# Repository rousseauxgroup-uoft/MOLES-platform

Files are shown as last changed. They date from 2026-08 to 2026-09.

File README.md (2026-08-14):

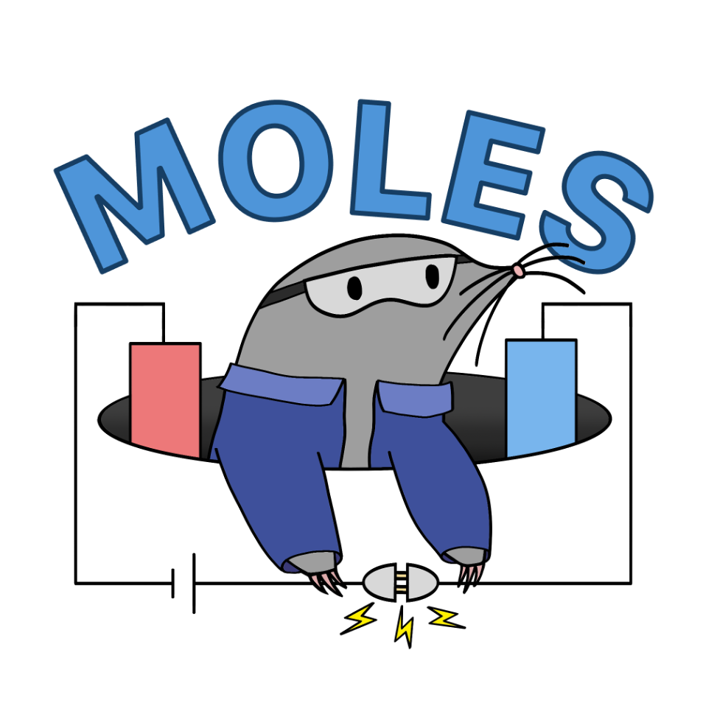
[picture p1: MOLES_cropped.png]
Moley the Mole, the mascot for MOLES


# MOLES
**M**odular **O**pen-source **L**aboratory for **E**lectrochemistry **S**creening

An affordable platform for small-scale electrosynthesis screening, enabled by an open-source potentiostat designed by the Acceleration Consortium and Matter Lab the University of Toronto (*Device*, **2025**, *3*, 100567, doi: 10.1016/j.device.2024.100567).

## Quickstart
- Clone or fork the MOLES repository.
- In your environment, run: ```pip install .``` in the terminal to install the package.
- Run the launcher with command: ```moles``` (or ```python -m moles```)
  - Shows every registered potentiostat with its live status (free, or in use by which app/experiment/user) and launches the apps below as independent processes
- Run electrolysis UI with command: ```moles-electrolysis```
  - Supported methods: **constant current**, **constant potential**, **alternating current** (up to 7 Hz via PID current control), and **alternating polarity** (up to 50 Hz via autonomous potential control)
- Run electroanalysis UI with command: ```moles-electroanalysis```
  - Tabbed interface for **cyclic voltammetry (CV)**, **differential pulse voltammetry (DPV)**, and an **analysis** workspace for overlaying, offsetting, smoothing, and labelling saved voltammograms

## More information
Check the [MOLES wiki](https://github.com/rousseauxgroup-uoft/MOLES-platform/wiki/MOLES-Wiki-Home) for more information regarding potentiostat ordering, hardware components, and other useful knowledge!

### Running multiple apps at once
MOLES apps can run in parallel on one machine: for example, an electrolysis experiment
on boards A–H while someone else runs CVs on board I. Serial ports are only
opened while an experiment is running, and each running experiment holds a
*claim* on its board (visible in the launcher and in each app's status
column), so starting an experiment on a board that is already in use is
refused with a message naming the current holder instead of interrupting it.
Claims left behind by a crashed app are detected automatically; the launcher's
"Force Release" button clears one manually if ever needed.

Much thanks to Sergio Pablo-García, Ángel García, Gun Deniz Akkoc, Malcolm Sim, Yang Cao, Maxine Somers, Chance Hattrick, Naruki Yoshikawa, Dominik Dworschak, Han Hao, and Alán Aspuru-Guzik for designing the first-generation open potentiostat platform that MOLES is based off.

*Note: Generative AI (Claude Code, Google Gemini, OpenAI GPT-5 Codex) was used for this project to assist with writing code.*

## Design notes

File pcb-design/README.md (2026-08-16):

## Ordering guide
Refer to the MOLES wiki.

## Board specifications
- 2 layers, FR4, 0.062" ±10%, ENIG (2 µ") surface finish, 1 oz outer copper
- Green LPI solder mask both sides, white silkscreen top only
- SMT top side only — 328 pads, 19.6 mil min pitch
- 306 holes across 10 drill sizes, smallest 9.8 mil; 7.8 mil min trace/space; tented vias
- IPC Class II, RoHS, electrical test yes, no impedance control
- Board 2.913" × 1.335", panelized 12-up on a 9.94" × 9.51" array, route-and-retain (you snap them apart)

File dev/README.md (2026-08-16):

# Developer utilities

Internal scripts used during MOLES development. **Not intended for end
users** — most require a connected potentiostat with a known serial port,
and the demo scripts contain placeholder values that need to be filled in
before they will run.

If you're a chemist trying to run experiments, use the GUI instead:

```bash
moles-electrolysis     # for electrosynthesis runs
moles-electroanalysis  # for cyclic voltammetry, differential pulse, and analysis
```

## What's here

| Script | Purpose |
| --- | --- |
| `demo_constant_potential.py` | Minimal scripted example: connect, hold a potential, then ramp a constant current. Useful as a starting point when writing your own automation around the driver. |
| `demo_multichannel.py` | Same demo, but discovers and connects to multiple potentiostats by serial port. Used to test parallel-channel logic. |
| `diagnose_cv_gain.py` | Logs raw gain indices and ADC readings during a CV to diagnose gain-switching glitches. |
| `diagnose_usb_capture.py` | Offline analyzer for a Wireshark/USBPcap `.pcapng` capture of the USB traffic. Reports where the data stream stops, bus errors, re-enumeration, whether the *host* stopped reading (canceled read pump), and how far the host app fell behind the device (backlog + loop-rate history). No hardware needed; reads a saved capture. |
| `repro_stall_cv.py` | **Hardware-facing.** Reproduces the extended-CV USB failure on demand by injecting a deliberate reader stall mid-CV. Use with a dummy cell, capture with USBPcap, and compare before/after firmware fixes. Never run automatically. |
| `verify_ac_math.py` | Standalone sanity check on the alternating-current waveform math (peak currents, frequency, duty cycle). No hardware needed. |
| `verify_R_u.py` | **Hardware-facing.** Validates `measure_R_u` against a resistor of known value wired as a dummy cell. Sweeps step sizes, repeats each, and reports the measured resistance three ways so noise bias is visible. Never run automatically. |

## The extended-CV failure signature (July 2026)

Root cause of the "Write timeout" / ClearCommError failures on long CV runs,
as established from a full USBPcap capture:

1. The host GUI/worker loop must sustain one iteration per 6 samples
   (41.7 it/s at 250 Hz). Late in long runs it slowed below that, and unread
   data piled up in the Windows serial buffer ("backlog").
2. At ~12 kB of backlog, Windows **canceled the read pump** and stopped
   reading from the device entirely.
3. The firmware's `CDC_Transmit_FS` then blocked forever in an unbounded
   busy-wait (`while (TxState != 0)`), freezing the main task.
4. The independent watchdog (IWDG, 2.05 s) reset the chip: the device dropped
   off the bus (XACT_ERROR), the port close babbled, and the device
   re-enumerated under a new address. The stale COM handle then produced the
   Write timeout / `ClearCommError` `ERROR_BAD_COMMAND` errors in Python.

A separate defect found in the same capture: when the host lags, the firmware
batch stepper reads *stale* waveform bytes instead of pausing, silently
applying ~24 s-old potentials. Fixes for all of this live in the host batch
loop (backlog guard, bigger pre-fill, bounded plot cost) and in the firmware
(bounded transmit waits, starvation guard, reset-cause diagnostics).

In a capture of a healthy run, `diagnose_usb_capture.py` should show no
canceled reads, backlog peaking well under 8 kB, and a loop rate pinned at
the required it/s for the whole run.

### Verifying the fixes (bench procedure, run manually)

1. Flash the updated firmware from `firmware/driver-master/potentiostat/`
   (build in STM32CubeIDE). The new diagnostics query (command 19) reports
   the reset cause and the dropped/starved counters.
2. With a dummy cell attached, run `repro_stall_cv.py --stall 8` while
   capturing with USBPcap.
   * Before the fixes this reproduces the failure: read pump canceled,
     ~2 s pause, XACT_ERROR, re-enumeration, dead COM port.
   * After the fixes the run either aborts cleanly (`HostLagError`, cell
     switched off) or completes; the device stays responsive and
     `read_diagnostics()` shows `watchdog_reset: False`.
3. After any *organic* failure, reconnect and call
   `Potentiostat.read_diagnostics()` before power-cycling — it tells you
   whether the firmware froze (watchdog), dropped data (host stopped
   reading), or starved (host too slow to supply the waveform).

## Before running the demos

Both `demo_*.py` scripts have `"/dev/tty.usbmodemREPLACE…"` placeholder
serial ports. Find your potentiostat's real port with:

```bash
python -m serial.tools.list_ports
```

(or open Device Manager → Ports on Windows). Replace the placeholder strings
with what you find, then run the script.

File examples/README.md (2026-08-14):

# Examples

Standalone scripts for analyzing MOLES output files. These do **not** require
a connected potentiostat — they read CSVs that MOLES has already saved.

## Scripts

### `plot_cyclic_voltammetry.py`

Interactive plotter for cyclic voltammograms.

```bash
python examples/plot_cyclic_voltammetry.py
```

Opens a file picker, asks whether you want to reference the plot to an
internal standard (e.g. Fc/Fc⁺), then renders the voltammogram with a
gradient colorbar indicating scan progress. Double-click a point to label it
with its potential and current.

Accepts both the modern MOLES CV format (with header row) and the older
two-column format (current, potential — no header). See
[`sample_data/Ag2.csv`](sample_data/Ag2.csv) for an example of the old format.

### `plot_electrolysis.py`

Plotter for electrolysis runs (constant-current, constant-potential,
alternating-current, alternating-polarity).

```bash
python examples/plot_electrolysis.py
```

Opens a file picker, then shows current, voltage, and cumulative charge over
time. Checkboxes let you toggle each series on or off.

Expects the MOLES electrolysis CSV format:
`Time (s), Current (mA), Voltage (V), Charge Passed (C)`.

## Sample data

[`sample_data/`](sample_data/) contains a small CV scan you can use to test
`plot_cyclic_voltammetry.py` without owning hardware.

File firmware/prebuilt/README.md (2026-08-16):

# Pre-built firmware

Compiled firmware for the open-source potentiostat used by MOLES. If you're
setting up a brand-new potentiostat and don't want to install a C/embedded
toolchain, flash one of these files directly onto the STM32G473 microcontroller.

## Files

- **`potentiostat.bin`** — raw binary. Most flashing tools accept this format.
- **`potentiostat.elf`** — ELF executable with symbols, debug info stripped.
  Some programmers (e.g. STM32CubeProgrammer) accept this directly.

Both files carry the same flash image; `.bin` is just the ELF's loadable
sections laid out flat. If you're unsure which to use, pick `.bin`.

## How to flash

1. Download [STM32CubeProgrammer](https://www.st.com/en/development-tools/stm32cubeprog.html)
   (free, from STMicroelectronics).
2. Put the potentiostat into bootloader mode by holding **SW1** while
   connecting it to USB.
3. In STM32CubeProgrammer, connect via USB DFU (you may need to refresh to see the USB device listed).
4. Open `potentiostat.bin`, click **Download** to flash the binary, and then **Verify** to check for a successful transfer.
5. Power-cycle the device by unplugging and replugging its USB connection.

After the power cycle the board enumerates as a USB CDC serial port
(VID `0x0483`, PID `0x5740`, "STM32 Virtual ComPort") and MOLES should connect
to it normally.

## Building from source

To modify the firmware, open the project in
[STM32CubeIDE](https://www.st.com/en/development-tools/stm32cubeide.html):
`File → Open Projects from File System →` then point it at
`firmware/driver-master/potentiostat/`. The IDE will regenerate the `Debug/`
build directory on first compile.

### Regenerating these files

From `firmware/driver-master/potentiostat/Debug/` after a successful build, with
`arm-none-eabi-objcopy` from the CubeIDE toolchain on your `PATH`:

```bash
arm-none-eabi-objcopy -O binary potentiostat_rev_B.elf ../../../prebuilt/potentiostat.bin
```

```bash
arm-none-eabi-objcopy --strip-debug potentiostat_rev_B.elf ../../../prebuilt/potentiostat.elf
```

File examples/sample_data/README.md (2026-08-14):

# Sample data

## `Ag2.csv` + `Ag2_params.csv`

A cyclic voltammogram scan, stored in the legacy two-column format
(current, potential — no header row). `Ag2_params.csv` contains the scan
parameters used (`start_V`, `min_V`, `max_V`, etc).

Use this with the example plotter to confirm your install is working:

```bash
python examples/plot_cyclic_voltammetry.py
# then select sample_data/Ag2.csv in the file picker
```

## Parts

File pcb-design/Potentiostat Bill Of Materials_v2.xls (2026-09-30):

Ref | Qnty | Value | Vendor | Mouser Part Number | Unit Price 1
C1, C9, C11, C12, C13, C15, C16, C17, C18, C27, C28, C31, C32, C33, C34, C35, C36, C37, C38, C39 | 20 | CL10B104KB8NNWC | Samsung Electro-Mechanics | 187-CL10B104KB8NNWC | 0.01
C2, C3, | 2 | CL21A475KAQNNNG | Samsung Electro-Mechanics | 187-CL21A475KAQNNNG | 0.10
C4, C5, C29, C40, | 4 | CL21A106KOQNNNG | Samsung Electro-Mechanics | 187-CL21A106KOQNNNG | 0.10
C7, C8, | 2 | CL10C120JB81PNC | Samsung Electro-Mechanics | 187-CL10C120JB81PNC | 0.10
C14, | 1 | GCM1885C2A560JA16D | Murata | 81-GCM1885C2A560JA6D | 0.10
C19, | 1 | GCM188R71H153JA37J | Murata | 81-GCM188R71H153JA7J | 0.20
C20, | 1 | GCM1885C1H162GA16D | Murata | 81-GCM1885C1H162GA6D | 0.23
C21, | 1 | GRM1885C1H161GA01J | Murata | 81-GRM1885C1H161GA1J | 0.23
C22, | 1 | GCM1885C2A160JA16D | Murata | 81-GCM1885C2A160JA6D | 0.10
C23, | 1 | GCM1885C1H1R6BA16D | Murata | 81-GCM1885C1H1R6BA6D | 0.30
C24, C25, | 2 | GRM1885C1H151JA01J | Murata | 81-GRM39C151J50J | 0.10
C26, C30, | 2 | CL10A106KQ8NNNC | Samsung Electro-Mechanics | 187-CL10A106KQ8NNNC | 0.13
C6, C10 | 1 | CL21A105KBCLNNC | Samsung Electro-Mechanics | 187-CL21A105KBCLNNC | 0.17
D1, | 1 | UHD111A-FKA-C3K23E1L3VG5ZB3Z3 | Cree LED | 941-UHD1AA3K3E3V53Z3 | 0.10
D2, D3, | 2 | SBA130CS_R1_00001 | Panjit | 241-SBA130CSR100001 | 0.30
D4, | 1 | SMAJ5.0A | Littelfuse | 576-SMAJ5.0A | 0.36
IC1, | 1 | STM32G473CCT3 | STMicroelectronics | 511-STM32G473CCT3 | 11.10
IC2, | 1 | MCP6476UT-E/LT | Microchip | 579-MCP6476UT-E/LT | 0.34
IC3, | 1 | W25Q512JVEIQ | Micron Technology | 454-W25Q512JVEIQ | 6.19
IC4, IC5, | 2 | OPA2182IDR | Texas Instruments | 595-OPA2182IDR | 3.54
IC6 | 1 | ADG601BRTZ | Analog Devices | 584-ADG601BRTZ-R7 | 3.01
IC7, | 1 | TLV9062QDRQ1 | Texas Instruments | 595-TLV9062QDRQ1 | 1.14
IC8, | 1 | AP7347DQ-33W5-7 | Diodes Incorporated | 621-AP7347DQ-33W5-7 | 0.70
J1, | 1 | 10118192-0001LF | Amphenol | 649-10118192-0001LF | 0.46
J2, | 1 | 20020327-C021B01LF | Amphenol | 649-220327-C021B01LF | 0.77
J3, | 1 | 20020327-C041B01LF | Amphenol | 649-220327-C041B01LF | 1.19
JP1, | 1 | RC0402FR-070RL | YAGEO | 603-RC0402FR-070RL | 0.10
K1, | 1 | 10129378-905001BLF | Amphenol | 649-1012937890501BLF | 0.17
L1, | 1 | LBC3225T6R8MR | Taiyo Yuden | 963-LBC3225T6R8MR | 0.18
L3, | 1 | MMZ1608S301ATA00 | TDK | 810-MMZ1608S301ATA00 | 0.10
L4, | 1 | ACM2012-121-2P-T002 | TDK | 810-ACM20121212PT002 | 0.46
L5, | 1 | FBMH1608HM221-T | Taiyo Yuden | 963-FBMH1608HM221-T | 0.14
PS1, | 1 | PDME1-S5-D5-S | CUI Inc. | 490-PDME1-S5-D5-S | 2.31
R1, R2, | 2 | RC0603FR-073K3L | YAGEO | 603-RC0603FR-073K3L | 0.10
R3, R4, | 2 | RT0603BRE07100KL | YAGEO | 603-RT0603BRE07100KL | 0.41
R5, R6, | 2 | RT0603BRD07300KL | YAGEO | 603-RT0603BRD07300KL | 0.33
R7, R8, R9, R11, R23, R24, | 6 | RC0603FR-071KL | YAGEO | 603-RC0603FR-071KL | 0.10
R14 | 1 | RC0603FR-071ML | YAGEO | 603-RC0603FR-071ML | 0.10
R10 | 1 | RC0603FR-07100RL | YAGEO | 603-RC0603FR-07100RL | 0.10
R15, R16, R17, R18, | 4 | RT0603BRE07300KL | YAGEO | 603-RT0603BRE07300KL | 0.49
R13, R19, R20, R21, R22, | 5 | RT0603BRD07100KL | YAGEO | 603-RT0603BRD07100KL | 0.33
R12, R25, R36, R37, | 4 | RC0603FR-0710KL | YAGEO | 603-RC0603FR-0710KL | 0.10
R26, R27, R33, R34, R39, R40, R41, R42, R43, | 9 | RC0603FR-07100RL | YAGEO | 603-RC0603FR-07100RL | 0.10
R28, | 1 | RC0603FR-07470RL | YAGEO | 603-RC0603FR-07470RL | 0.10
R29, R30, | 2 | RC0603FR-07750RL | YAGEO | 603-RC0603FR-07750RL | 0.10
R31, | 1 | RC0603FR-074K7L | YAGEO | 603-RC0603FR-074K7L | 0.10
R32, | 1 | RC0603FR-070RL | YAGEO | 603-RC0603FR-070RL | 0.10
R35, R38, | 2 | RC0603FR-077K5L | YAGEO | 603-RC0603FR-077K5L | 0.10
SW1, SW2, | 2 | TS02-66-150-BK-260-LCR-D | CUI Inc. | 179-TS0266150BK260LC | 0.12
U1, | 1 | TMUX6212PWR | Texas Instruments | 595-TMUX6212PWR | 5.92
U2, | 1 | USBUF02W6 | STMicroelectronics | 511-USBUF02W6 | 0.82
U3, | 1 | SHTC3 | Sensirion | 403-SHTC3 | 3.04
X1, | 1 | CM8V-T1A-32.768kHz-9pF-20PPM-TB-QC | Micro Crystal | 428-202817-MC01 | 0.69
 |  |  |  |  | 47.79

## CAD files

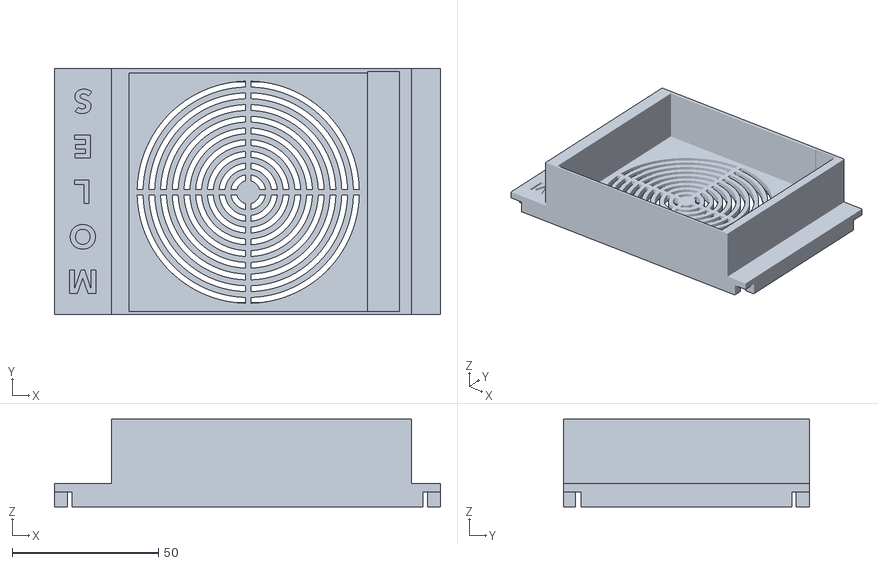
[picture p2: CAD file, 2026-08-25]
3D-print-files/Potentiostat-case-lid-fan-grill.stl
132.0 x 84.0 x 30.0

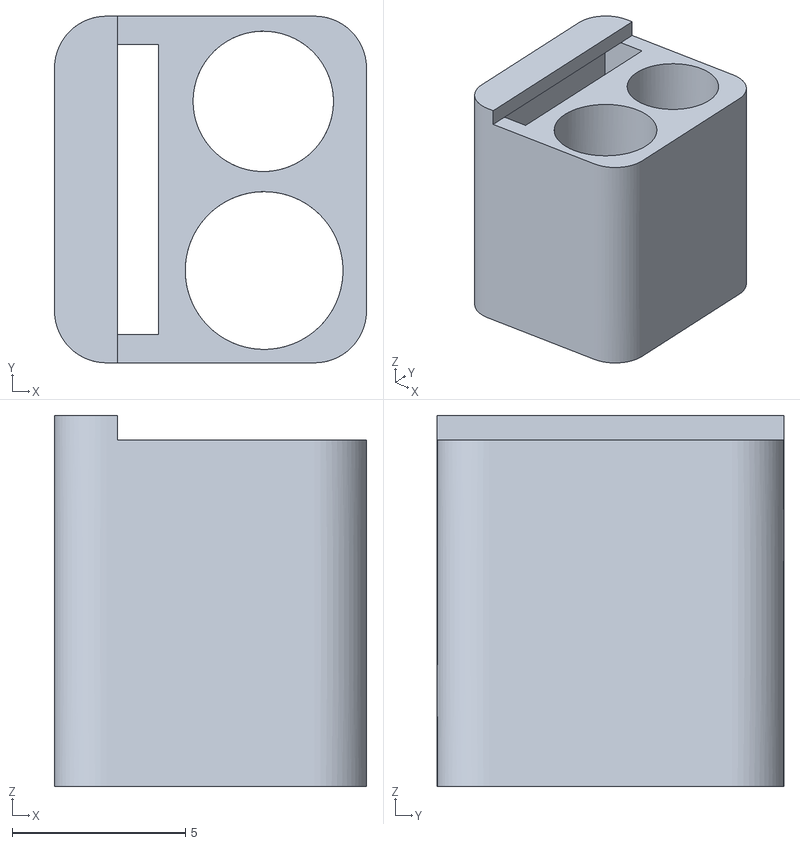
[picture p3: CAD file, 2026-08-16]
3D-print-files/CV-electrode-holders-Pt-GC-AgRef.stl
9.00 x 10.0 x 10.7

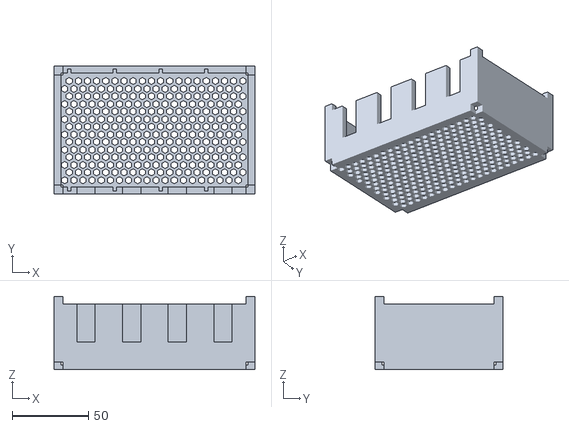
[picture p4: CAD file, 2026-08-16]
3D-print-files/Potentiostat-4x-cartridge-case.stl
132.0 x 84.0 x 48.0

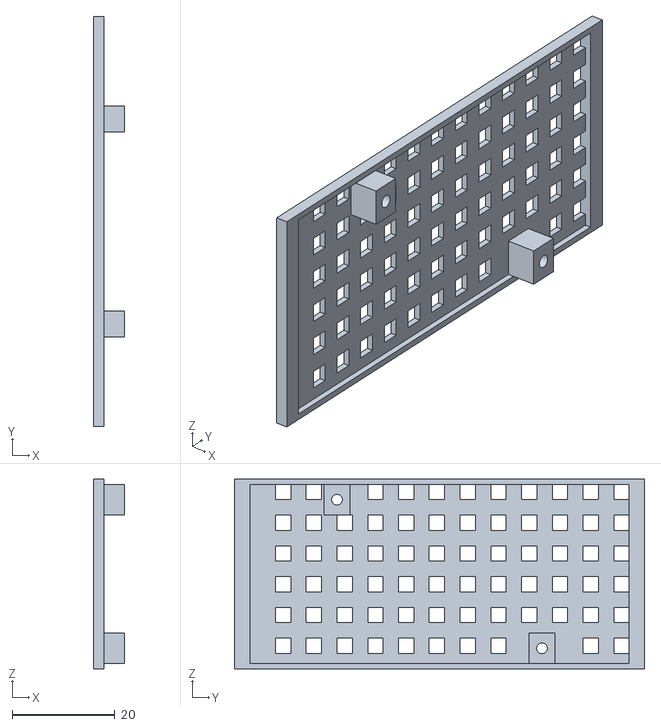
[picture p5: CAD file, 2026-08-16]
3D-print-files/Potentiostat-cartridge-tray.stl
6.00 x 80.0 x 37.0

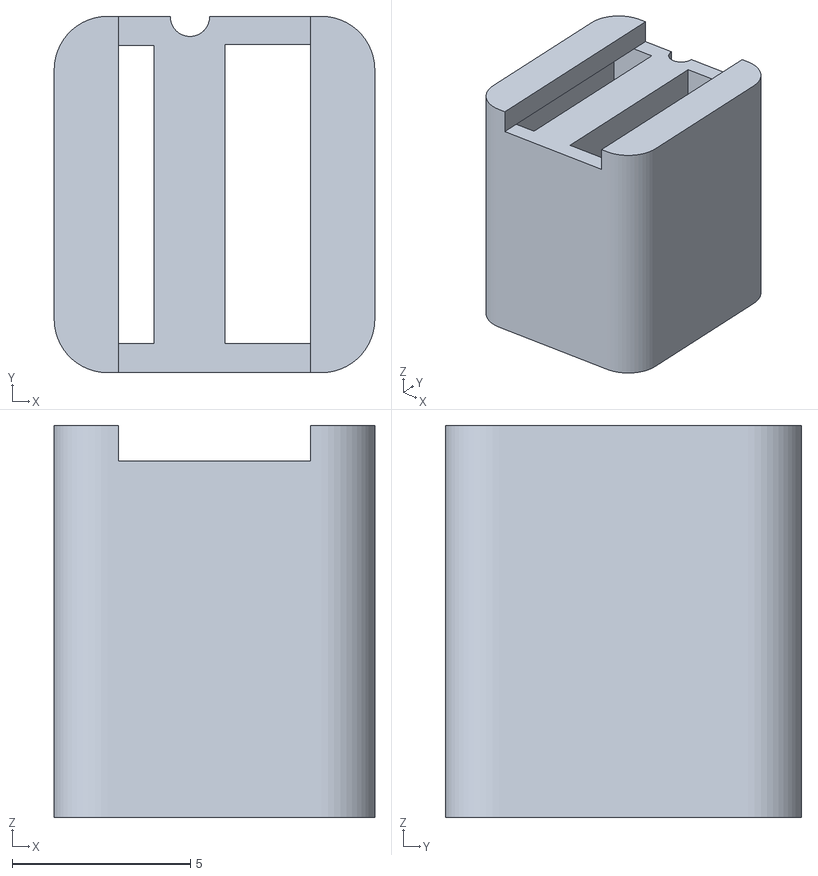
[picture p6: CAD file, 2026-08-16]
3D-print-files/2-electrode-holder.stl
9.00 x 10.0 x 11.0

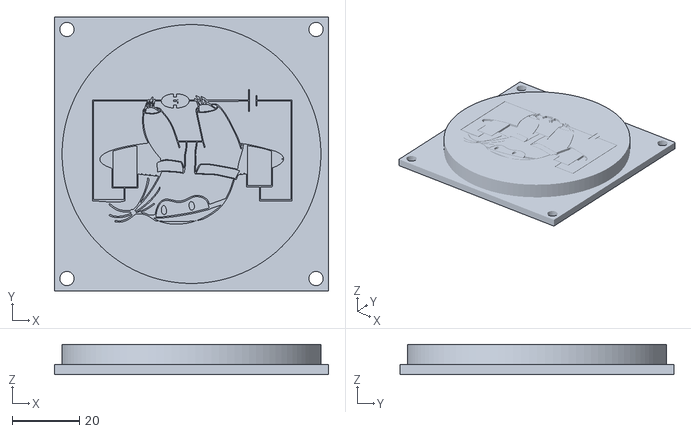
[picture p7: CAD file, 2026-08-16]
3D-print-files/Potentiostat-case-fan-cover.stl
81.5 x 81.5 x 9.00

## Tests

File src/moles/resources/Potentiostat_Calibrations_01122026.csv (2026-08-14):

Potentiostat ID | Slope | Intercept | Comments
PS A | 1.093 | 0.02 | verified
PS B | 1.093 | 0.01 | verified
PS C | 1.092 | 0.01 | verified
PS D | 1.092 | -0.018 | verified
PS E | 1.097 | 0.035 | verified
PS F | 0.997 | 0.00 | verified
PS G | 1.024 | 0.02 | verified
PS H | 1.099 | 0.037 | verified

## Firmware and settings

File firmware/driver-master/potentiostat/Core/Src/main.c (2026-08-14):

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
/* Includes ------------------------------------------------------------------*/
#include "main.h"
#include "cmsis_os.h"
#include "app_fatfs.h"
#include "usb_device.h"

/* USER CODE BEGIN Includes */
#include "user.h"
/* USER CODE END Includes */

ADC_HandleTypeDef hadc1;
ADC_HandleTypeDef hadc3;
ADC_HandleTypeDef hadc5;
DMA_HandleTypeDef hdma_adc1;
DMA_HandleTypeDef hdma_adc3;
DMA_HandleTypeDef hdma_adc5;

CORDIC_HandleTypeDef hcordic;

CRC_HandleTypeDef hcrc;

DAC_HandleTypeDef hdac1;
DAC_HandleTypeDef hdac2;
DAC_HandleTypeDef hdac3;

FMAC_HandleTypeDef hfmac;

I2C_HandleTypeDef hi2c2;

IWDG_HandleTypeDef hiwdg;

LPTIM_HandleTypeDef hlptim1;

OPAMP_HandleTypeDef hopamp3;

RNG_HandleTypeDef hrng;

RTC_HandleTypeDef hrtc;

SPI_HandleTypeDef hspi1;

TIM_HandleTypeDef htim1;
TIM_HandleTypeDef htim5;

UART_HandleTypeDef huart1;

DMA_HandleTypeDef hdma_memtomem_dma1_channel7;
/* Definitions for defaultTask */
osThreadId_t defaultTaskHandle;
const osThreadAttr_t defaultTask_attributes = {
  .name = "defaultTask",
  .priority = (osPriority_t) osPriorityNormal,
  .stack_size = 128 * 4
};
void SystemClock_Config(void);
static void MX_GPIO_Init(void);
static void MX_DMA_Init(void);
static void MX_ADC1_Init(void);
static void MX_CRC_Init(void);
static void MX_DAC1_Init(void);
static void MX_DAC2_Init(void);
static void MX_SPI1_Init(void);
static void MX_TIM1_Init(void);
static void MX_OPAMP3_Init(void);
static void MX_I2C2_Init(void);
static void MX_DAC3_Init(void);
static void MX_RTC_Init(void);
static void MX_USART1_UART_Init(void);
static void MX_CORDIC_Init(void);
static void MX_FMAC_Init(void);
static void MX_RNG_Init(void);
static void MX_LPTIM1_Init(void);
static void MX_TIM5_Init(void);
static void MX_ADC5_Init(void);
static void MX_IWDG_Init(void);
static void MX_ADC3_Init(void);
void StartDefaultTask(void *argument);

/* USER CODE BEGIN 0 */

/* Why the MCU last rebooted, captured from the sticky reset flags at boot and
 * reported to the host by the diagnostics query. Lets the software tell a
 * watchdog reset (firmware froze mid-run) from a normal power-up. */
uint32_t reset_cause_raw = 0;

#define USB_GPIO_Port GPIOA
#define USB_DM_Pin GPIO_PIN_11
#define USB_DP_Pin GPIO_PIN_12

static void DisconnectUsbPort(void)
{
	GPIO_InitTypeDef GPIO_InitStruct = {0};

	/*Configure GPIO pins : USB_DM_Pin PA11 USB_DP_Pin */

	GPIO_InitStruct.Pin = USB_DM_Pin|USB_DP_Pin;
	GPIO_InitStruct.Mode = GPIO_MODE_OUTPUT_OD;
	GPIO_InitStruct.Pull = GPIO_NOPULL;
	GPIO_InitStruct.Speed = GPIO_SPEED_FREQ_LOW;

	HAL_GPIO_Init(USB_GPIO_Port, &GPIO_InitStruct);
}
/* USER CODE END 0 */

/**
  * @brief  The application entry point.
  * @retval int
  */
int main(void)
 {
  /* USER CODE BEGIN 1 */

  /* Snapshot the reset-cause flags first, then clear them so the next boot
   * reports only its own cause. */
  reset_cause_raw = RCC->CSR;
  __HAL_RCC_CLEAR_RESET_FLAGS();

  /* USER CODE END 1 */

  /* MCU Configuration--------------------------------------------------------*/

  /* Reset of all peripherals, Initializes the Flash interface and the Systick. */
  HAL_Init();

  /* Configure the system clock */
  SystemClock_Config();

  /* Initialize all configured peripherals */
  MX_GPIO_Init();
  DisconnectUsbPort();
  MX_DMA_Init();
  MX_ADC1_Init();
  MX_CRC_Init();
  MX_DAC1_Init();
  MX_DAC2_Init();
  MX_SPI1_Init();
  MX_USB_Device_Init();
  MX_TIM1_Init();
  MX_OPAMP3_Init();
  MX_I2C2_Init();
  MX_DAC3_Init();
  MX_RTC_Init();
  MX_USART1_UART_Init();
/*  if (MX_FATFS_Init() != APP_OK) {
    Error_Handler();
  }*/
  MX_CORDIC_Init();
  MX_FMAC_Init();
  MX_RNG_Init();
  MX_LPTIM1_Init();
  MX_TIM5_Init();
  MX_ADC5_Init();
  MX_IWDG_Init();
  MX_ADC3_Init();
  /* USER CODE BEGIN 2 */

  DAC_Init(GetDAC_Cfg_Dflt());
  ADC_Init(GetAnalog_cfg_dflt());
  BlinkLed_Init();
  Humidity_Sensor_Task(&hi2c2);	// Function Initialization for SHTC3 humidity and temperature sensor
  Set_TIA_Gain(eTIA_SW_GAIN_100); // Selected resistor
  HAL_GPIO_WritePin(CE_EN_GPIO_Port, CE_EN_Pin, 0); // Set switch Off

  /* USER CODE END 2 */

  /* Init scheduler */
  osKernelInitialize();

  /* USER CODE BEGIN RTOS_MUTEX */
  /* add mutexes, ... */
  /* USER CODE END RTOS_MUTEX */

  /* USER CODE BEGIN RTOS_SEMAPHORES */
  /* add semaphores, ... */
  /* USER CODE END RTOS_SEMAPHORES */

  /* USER CODE BEGIN RTOS_TIMERS */
  /* start timers, add new ones, ... */
  /* USER CODE END RTOS_TIMERS */

  /* USER CODE BEGIN RTOS_QUEUES */
  /* add queues, ... */
  /* USER CODE END RTOS_QUEUES */

  /* Create the thread(s) */
  /* creation of defaultTask */
  defaultTaskHandle = osThreadNew(StartDefaultTask, NULL, &defaultTask_attributes);

  /* USER CODE BEGIN RTOS_THREADS */
  const osThreadAttr_t PstatTask_attributes = {
    .name = "Pstat_Task",
    .priority = (osPriority_t) osPriorityAboveNormal,
    .stack_size = 512
  };

//  const osThreadAttr_t LedBlinkTask_attributes = {
//    .name = "Led_Blink_Task",
//    .priority = (osPriority_t) osPriorityBelowNormal,
//    .stack_size = 512
//  };

//  const osThreadAttr_t Triangle_attributes = {
//    .name = "Triangle_Task",
//    .priority = (osPriority_t) osPriorityNormal,
//    .stack_size = 512
//  };

  osThreadId_t pstat_thread = osThreadNew(Pstat_RunTime, NULL, &PstatTask_attributes);
  UNUSED(pstat_thread);

 // osThreadId_t LedBlink_thread = osThreadNew(BlinkLed_RunTime, NULL, &LedBlinkTask_attributes);
 // UNUSED(LedBlink_thread);

// osThreadId_t Triangle_thread = osThreadNew(Triangle_Test, NULL, &Triangle_attributes);
// UNUSED(Triangle_thread);

  /* USER CODE END RTOS_THREADS */

  /* USER CODE BEGIN RTOS_EVENTS */
  /* add events, ... */
  /* USER CODE END RTOS_EVENTS */

  /* Start scheduler */
  osKernelStart();

  /* We should never get here as control is now taken by the scheduler */
  /* Infinite loop */
  /* USER CODE BEGIN WHILE */
  while (1)
  {
    /* USER CODE END WHILE */

    /* USER CODE BEGIN 3 */
  }
  /* USER CODE END 3 */
}

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
/* USER CODE BEGIN Header_StartDefaultTask */
/**
  * @brief  Function implementing the defaultTask thread.
  * @param  argument: Not used
  * @retval None
  */
/* USER CODE END Header_StartDefaultTask */
void StartDefaultTask(void *argument)
{
  /* USER CODE BEGIN 5 */
  /* Infinite loop */
  for(;;)
  {
    osDelay(1);
  }
  /* USER CODE END 5 */
}

/**
  * @brief  Period elapsed callback in non blocking mode
  * @note   This function is called  when TIM2 interrupt took place, inside
  * HAL_TIM_IRQHandler(). It makes a direct call to HAL_IncTick() to increment
  * a global variable "uwTick" used as application time base.
  * @param  htim : TIM handle
  * @retval None
  */
void HAL_TIM_PeriodElapsedCallback(TIM_HandleTypeDef *htim)
{
  if (htim->Instance == TIM2) {
    HAL_IncTick();
  }
}

/**
  * @brief  This function is executed in case of error occurrence.
  * @retval None
  */
void Error_Handler(void)
{
  /* USER CODE BEGIN Error_Handler_Debug */
  /* User can add his own implementation to report the HAL error return state */
  __disable_irq();
  while (1)
  {
  }
  /* USER CODE END Error_Handler_Debug */
}

#ifdef  USE_FULL_ASSERT
/**
  * @brief  Reports the name of the source file and the source line number
  *         where the assert_param error has occurred.
  * @param  file: pointer to the source file name
  * @param  line: assert_param error line source number
  * @retval None
  */
void assert_failed(uint8_t *file, uint32_t line)
{
  /* USER CODE BEGIN 6 */
  /* User can add his own implementation to report the file name and line number,
     ex: printf("Wrong parameters value: file %s on line %d\r\n", file, line) */
  /* USER CODE END 6 */
}
#endif /* USE_FULL_ASSERT */

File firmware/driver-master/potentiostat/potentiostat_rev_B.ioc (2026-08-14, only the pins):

Mcu.UserName=STM32G473CCTx
PA1.Signal=ADC1_IN2
PA10.Signal=USART1_RX
PA11.Signal=USB_DM
PA12.Signal=USB_DP
PA13.Signal=SYS_JTMS-SWDIO
PA14.Signal=SYS_JTCK-SWCLK
PA15.GPIO_Label=FLASH_NSS
PA15.Signal=GPIO_Output
PA4.Signal=COMP_DAC11_group
PA6.Signal=COMP_DAC21_group
PA8.Signal=I2C2_SDA
PA9.Signal=I2C2_SCL
PB0.Signal=ADC3_IN12
PB1.Signal=OPAMP3_VOUT
PB10.GPIO_Label=IVG2
PB10.Signal=GPIO_Output
PB11.GPIO_Label=IVG3
PB11.Signal=GPIO_Output
PB12.GPIO_Label=IVG4
PB12.Signal=GPIO_Output
PB13.GPIO_Label=CE_EN
PB13.Signal=GPIO_Output
PB3.Signal=SPI1_SCK
PB4.Signal=SPI1_MISO
PB5.Signal=SPI1_MOSI
PB6.Signal=USART1_TX
PB7.GPIO_Label=BLUE_LED
PB7.Signal=GPIO_Output
PB9.GPIO_Label=IVG1
PB9.Signal=GPIO_Output
PC14-OSC32_IN.Signal=RCC_OSC32_IN
PC15-OSC32_OUT.Signal=RCC_OSC32_OUT
PF0-OSC_IN.GPIO_Label=RED_LED
PF0-OSC_IN.Signal=GPIO_Output
PF1-OSC_OUT.GPIO_Label=GREEN_LED
PF1-OSC_OUT.Signal=GPIO_Output

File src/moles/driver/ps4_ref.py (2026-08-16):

#!/usr/bin/env python3
"""Serial driver for the STM32G473-based open-source potentiostat.

Original work by Han Hao, Sergio Pablo-García, and Gun Deniz Akkoc, from the
open-source potentiostat platform described in Device 2025, 3, 100567
(doi: 10.1016/j.device.2024.100567). Licensed under the Apache License,
Version 2.0.

This file has been modified for the MOLES project by. The
changes harden the original command set:
  - logging via the standard library in place of print statements
  - SerialReadTimeout / SerialAckError and retry helpers, so a short or
    unacknowledged serial read is retried and reported rather than raising
    an opaque IndexError partway through an experiment
  - _safe_open_switch(), which matches the DAC to the measured cell
    potential before opening the CE-WE switch, suppressing the output spike
  - stream_voltage_batch(), for gapless upload of a precomputed waveform

Original header:
    2023-08-30
    deniz
"""
import logging
import serial
import threading
import time
import numpy as np
from collections import deque
from enum import IntEnum
from pathlib import Path
# import tomllib
import sys
from typing import Union
from .proc_echem import *
from typing import List

logger = logging.getLogger(__name__)


class SerialReadTimeout(Exception):
    """Raised when a serial read returns fewer bytes than expected, even after a retry."""


class SerialAckError(Exception):
    """Raised when the device does not acknowledge a command with "OK", even
    after the command has been re-sent once. Means the command may not have
    taken effect on the hardware."""


class Commands(IntEnum):
    """Contains index for each serial command

    """
    READ_ADC = 1
    WRITE_DAC = 2
    READ_DAC = 3
    WRITE_SWITCH = 4
    WRITE_GAIN = 5
    EXECUTE_VOLTAGE_BATCH = 7
    _WRITE_BUFFER = 8
    _READ_BUFFER = 9
    WRITE_CURRENT_HOLD = 10
    _RESET_BUFFER = 11
    WRITE_SAMPLE_COUNT = 12
    WRITE_AUTO_GAIN = 13
    READ_ANALOG_GAIN = 14
    READ_AUTO_GAIN = 15
    READ_GAIN = 16
    READ_SWITCH = 17
    STOP_CURRENT_HOLD = 18
    READ_DIAGNOSTICS = 19
    # Self-framing positional buffer write ([u16 len][u16 pos] + data);
    # requires July 2026 firmware. See stream_voltage_batch.
    _WRITE_BUFFER_AT = 20
    # Firmware-timed step-response capture for the R_u measurement
    # ([u32 n_samples][u32 period_us]); requires Aug 2026 firmware. The
    # driver probes for it once and falls back to the serial burst.
    STEP_CAPTURE = 21

    
class Resistors():
    """Contains index information of resistor values along with the resistance values for gain.
    This information is then used for V to I conversion (simple V=IR)
    """
    R_100 = 0
    R_1K = 1
    R_10K = 2
    R_100K = 3
    R_1M = 4
    #R_10M = 5

class ADC():
    WE_OUT = 0 #WE-CE potential for conversion to current with resistor multiplier.
    RE_OUT = 1 #WE-RE potential
    VREF = 2
    TEMP = 3 #Temperature
    HUMID = 4 #Humidity

class DAC():
    CE_IN = 0 #RE-WE
    A_REF = 1
    V_AN = 2


class SwitchState(IntEnum):
    On = 1 #CE and WE connected
    Off = 0 #CE and WE disconnected

# Bench-measured output limits (July 2026, dummy-cell tests): the output
# amplifier saturates near +/-4.6 V (-4.60/+4.62 V on a 450-ohm dummy cell)
# and the USB supply tops out near 33 mA (3.35 V on 100 ohm). Setpoints beyond
# these cannot be reached even in an ideal cell; real cells saturate earlier
# because solution resistance and counter-electrode overpotential consume part
# of the headroom. The software input range (+/-5 V) is wider than this, so
# the UIs warn before starting a run whose setpoints exceed the threshold.
HW_VOLTAGE_COMPLIANCE_V = 4.6
VOLTAGE_WARN_THRESHOLD_V = 4.5

# Firmware step-capture (CMD_STEP_CAPTURE) defaults for the R_u measurement:
# 25 us sampling (the firmware's floor) over 150 ms. The fast end matters
# most: small analytical electrodes give R_u*C_dl of only ~20-50 us
# (bench 2026-08-15), so every microsecond of the first samples counts;
# the long tail pins down the faradaic baseline.
RU_CAPTURE_PERIOD_US = 25
RU_CAPTURE_MS = 150.0

# The switch-close instrument artifact the control capture measures lives in
# the first moments of a trace; beyond this window the control is only noise
# and OCP drift, which subtracting would inject into the step traces.
RU_ARTIFACT_WINDOW_MS = 2.0

# The firmware's KADC16: raw 16-bit ADC counts to ADC volts (3.3 V full scale)
ADC16_COUNTS_TO_V = 3.3 / 65535.0


class Potentiostat():
    serial = None
    serial_port = None
    device_ID = 0
    baudrate = 115200
    _chunk_size = 254 #number of bytes that can be communicated at once minus 2 (for ID and command bytes) !!!CONFIG
    _vin_lims = [-5,5]
    _vout_lims = [0,3.3]
    _auto_gain = False
    _switch_state = False
    _rx_buffer_size = 24000 #rx buffer size of the pstat
    _tx_buffer_size = 64000 #tx buffer size of the pstat
    # Whether the connected firmware has CMD_STEP_CAPTURE: None until the
    # first R_u measurement probes for it, then cached for the connection.
    _step_capture_supported = None

    res_vals    = {Resistors.R_100: 1e2,
                Resistors.R_1K: 1e3,
                Resistors.R_10K: 1e4,
                Resistors.R_100K: 1e5,
                Resistors.R_1M: 1e6,
                #R_10M: 1e7,
    }
    
    def _select_resistor(self, current):
        """_summary_

        Args:
            current (float): Target Ampere

        Returns:
            Resistors: Best resistance for highest gain without saturation of the ADC
        """
        max_currents = [0.05, 0.005, 0.0005, 0.00005, 0.000005, 0.0000005] #in Amps
        #max_currents = [0.05, 0.005, 0.0005, 0.00005, 0.000005, 0.0000005, 0.00000005] #in Amps (with 10M resistor)
        for i in range(len(max_currents)):
            if abs(current) > (max_currents[i] * 0.9):
                if i < 1: return 0
                return i-1
        return Resistors.R_1M

    def _select_100ohm_resistor(self, current):
        """_summary_

        Args:
            current (float): Target Ampere

        Returns:
            Resistors: R_100 ohm resistor for electrosynthesis-scale currents (mA level)
        """
        # Hardware appears stuck on R_100, force selection.
        return Resistors.R_100


    class Errors(IntEnum):
        NO_ERROR = 0
        ERROR = 1

    def __init__(self,serial_port='/dev/ttyACM1',baudrate=115200,device_ID = 1):
        self.serial_port = serial_port
        self.baudrate = baudrate
        self.device_ID = device_ID
        # Serializes every command/response transaction on this port. Multiple
        # threads can legitimately reach for the same device (experiment loop,
        # emergency cleanup at shutdown, reconnect) and interleaved commands
        # desync the request/response protocol. RLock so composite operations
        # (e.g. a whole voltage batch) can hold it across nested calls.
        self._port_lock = threading.RLock()
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

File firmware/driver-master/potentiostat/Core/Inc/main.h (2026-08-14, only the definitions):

#define RED_LED_Pin GPIO_PIN_0
#define RED_LED_GPIO_Port GPIOF
#define GREEN_LED_Pin GPIO_PIN_1
#define GREEN_LED_GPIO_Port GPIOF
#define IVG2_Pin GPIO_PIN_10
#define IVG2_GPIO_Port GPIOB
#define IVG3_Pin GPIO_PIN_11
#define IVG3_GPIO_Port GPIOB
#define IVG4_Pin GPIO_PIN_12
#define IVG4_GPIO_Port GPIOB
#define CE_EN_Pin GPIO_PIN_13
#define CE_EN_GPIO_Port GPIOB
#define FLASH_NSS_Pin GPIO_PIN_15
#define FLASH_NSS_GPIO_Port GPIOA
#define BLUE_LED_Pin GPIO_PIN_7
#define BLUE_LED_GPIO_Port GPIOB
#define IVG1_Pin GPIO_PIN_9
#define IVG1_GPIO_Port GPIOB

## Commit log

2026-08-16 Added Gerber files and BOM for potentiostat PCBs
    [Potentiostat Bill Of Materials.xls]
2026-08-16 Added Gerbers, BOM, and README
    [Potentiostat Bill Of Materials.xls]
2026-08-25 Added fan grill lid STL
    [Potentiostat-case-lid-fan-grill.stl]
2026-09-30 Replace BOM with updated version without box and xell adaptro
    [Potentiostat Bill Of Materials_v2.xls]
2026-10-21 Sync with MOLES development: Data Analysis app, installers, firmware 1.8
    - Data Analysis app for comparing, labelling and exporting CV/DPV data
    - Windows and macOS installers with an ask-first update check
    - Firmware 1.2-1.8: misalignment-proof waveform uploads, corrected
    current ranges with auto-ranging, R_u step capture, on-board iR
    compensation
    - Driver, method and app fixes; electrolysis emergency-stop guardian
    - pcb-design/ and 3D-print-files/ unchanged

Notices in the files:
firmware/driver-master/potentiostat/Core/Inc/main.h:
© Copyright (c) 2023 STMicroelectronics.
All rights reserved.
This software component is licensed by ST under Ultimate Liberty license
